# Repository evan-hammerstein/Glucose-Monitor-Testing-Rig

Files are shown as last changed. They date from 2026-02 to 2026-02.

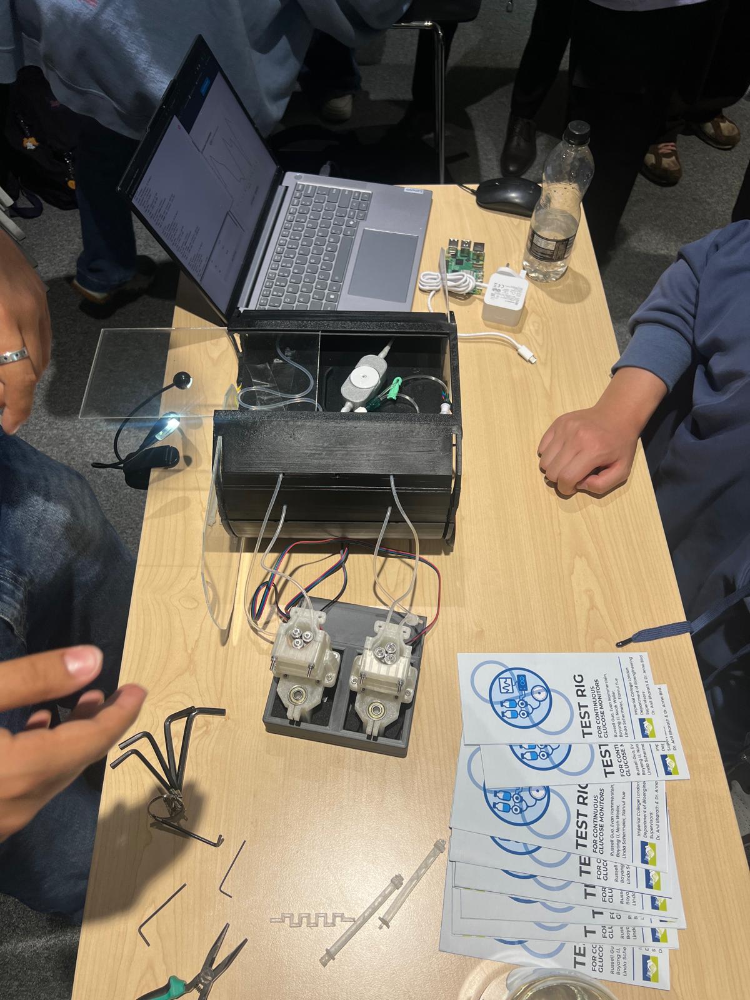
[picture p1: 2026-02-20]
real_build.jpeg

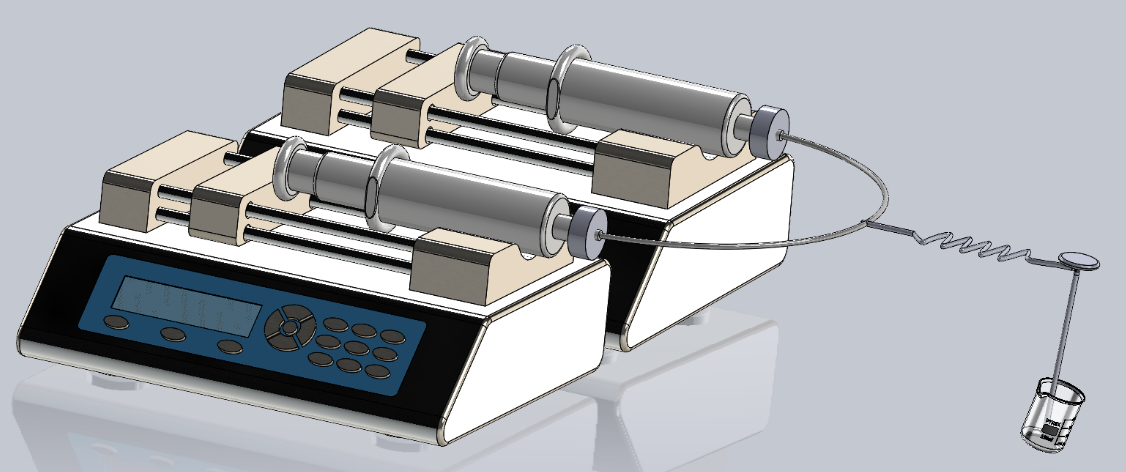
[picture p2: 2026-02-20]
syringe_pump_model.jpg

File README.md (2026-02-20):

# Design and Development of a Test Rig for Continuous Glucose Monitors (CGM)

**Associated Presentations and Full Project Report (Release):**

https://github.com/evan-hammerstein/Glucose-Monitor-Testing-Rig/releases/tag/Release
https://prezi.com/p/qimv-nsshvhj/?present=1

Imperial College London
MEng Bioengineering Final Year Project
Supervisors: Dr. Anil Bharath, Dr. Anna Bird

This repository contains all code, CAD models, control algorithms, circuit schematics, and supporting files for the design and validation of a cost-effective automated CGM test rig.

The full academic report is included in this repository and documents the complete design process and validation results .

---

# Project Overview

Continuous Glucose Monitors are increasingly used in diabetes management. However, early-stage CGM validation often relies on manual in-vitro testing with limited dynamic capability.

This project designed and implemented:

• A low-cost automated CGM test rig
• Programmable glucose concentration control
• Two fluid delivery architectures
• Custom passive mixing solutions
• A CGM-compatible fluid interface
• An Arduino-based control system
• A desktop user interface for simulation and automation

Two complete systems were developed:

1. Binary system
   Alternates between two fixed glucose concentrations.

2. Dynamic system
   Recreates physiologically realistic glucose trajectories using real-time flow rate control based on the Padova model.

---

# Key Features

• Fully automated glucose profile generation
• Real-time pump control via Arduino
• Open-source peristaltic pump integration
• Custom 3D-printed passive mixers
• CGM interface designed for leak-free operation
• Electron-based desktop UI
• Integration with FreeStyle Libre 2 CGM
• Modular design using Luer-lock fluidics

---

# Repository Structure

/3D-Models
• Passive mixer designs
• CGM interface designs
• Peristaltic pump customizations
• STL and CAD files

/arduino
• Binary valve control code
• Dynamic dual-pump control algorithm
• RPM mapping implementation
• Delay synchronization logic

/electron-ui
• User interface for profile selection
• Parameter configuration
• Glucose trajectory visualization

/python
• Padova model integration
• Example glucose profiles
• CSV generation for simulation

/circuits
• Valve control schematics
• Dual pump A4988 driver circuit
• Wiring diagrams

/report
• Final project report (PDF)

---

# System Architecture

Binary System

Syringe Pump → Solenoid Valves → CGM Interface → CGM Reader

Dynamic System

Peristaltic Pump 1
Peristaltic Pump 2
→ Y-junction → Passive Mixer → CGM Interface → CGM Reader

The dynamic system adjusts the ratio of high and low glucose reservoirs in real time to match a target glucose concentration trajectory.

---

# Control Algorithm Summary

Inputs:

• Composite flow rate
• Tubing geometry
• Reservoir concentrations
• Target glucose profile

Outputs:

• Individual pump flow rates
• Stepper motor RPM
• Pump activation delay

The algorithm ensures:

• Constant total flow rate
• Complementary pump behavior
• Synchronized arrival at mixing junction

Edge cases such as zero-flow conditions are handled explicitly.

---

# Hardware Components

• Arduino Uno
• A4988 stepper motor drivers
• NEMA 17 stepper motors
• Open-source peristaltic pump
• Solenoid valves
• Silicone tubing
• Luer connectors
• 3D-printed CGM interface
• FreeStyle Libre 2 CGM

Full bill of materials is included in the repository.

---

# Mixer Designs

Four passive mixer iterations were evaluated:

• Stepwise geometry
• Sinusoidal channel
• Helical in-line mixer
• Self-constructed multi-loop mixer

The self-constructed multi-loop mixer provided:

• Effective mixing
• Ease of fabrication
• Leak-free integration
• Compatibility with standard lab printers

---

# Validation Highlights

• Pump RPM vs flow rate linear correlation: R = 0.9998
• Mixer absorbance matched magnetically stirred control
• Open-channel CGM interface demonstrated leak-free operation
• Binary system successfully reproduced square-wave profiles
• Dynamic system tracked programmed glucose trajectories

Observed deviations were attributed to:

• CGM internal processing
• Diffusion delays
• Environmental effects
• Delay amplification under certain parameter combinations

---

# How to Use

1. Assemble hardware using provided CAD and material lists
2. Upload Arduino firmware
3. Connect pumps and drivers per circuit diagrams
4. Launch Electron UI
5. Select or generate glucose profile
6. Run system
7. Monitor CGM output via xDrip+

---

# Applications

• Early-stage CGM validation
• Sensor accuracy testing
• Interference testing
• Algorithm verification
• Closed-loop system research
• CGM cybersecurity testing
• Hybrid closed loop simulation

---

# Future Improvements

• Improved delay minimization algorithm
• Automatic optimization of reservoir concentrations
• Environmental control integration
• Expanded flow rate characterization
• Diffusion vs advection quantification
• Closed-loop insulin simulation support

---

# Acknowledgements

Imperial College London
Department of Bioengineering

Supervisors:
Dr. Anil Bharath
Dr. Anna Bird

IN-CYPHER Programme

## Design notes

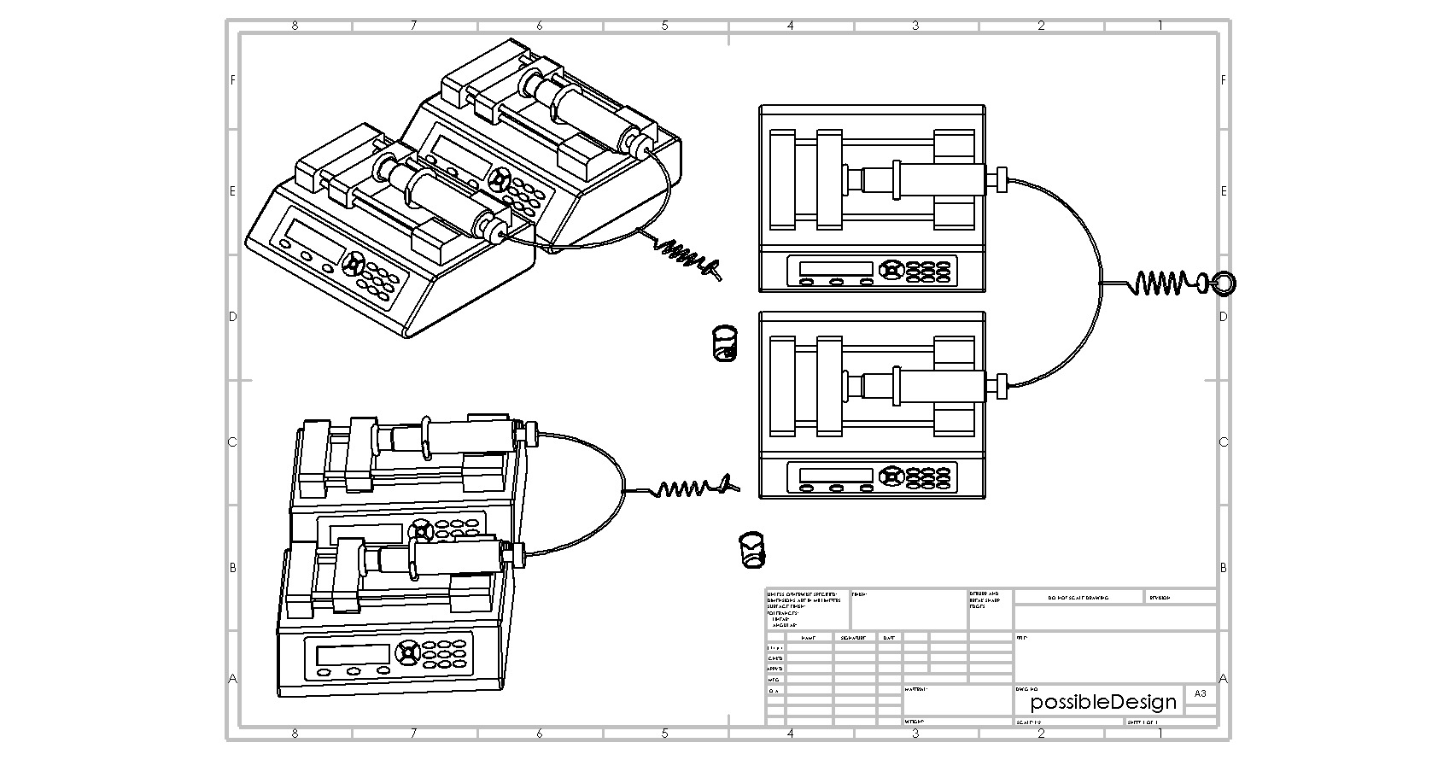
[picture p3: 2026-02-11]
Working in progress casing/possibleDesign.JPG

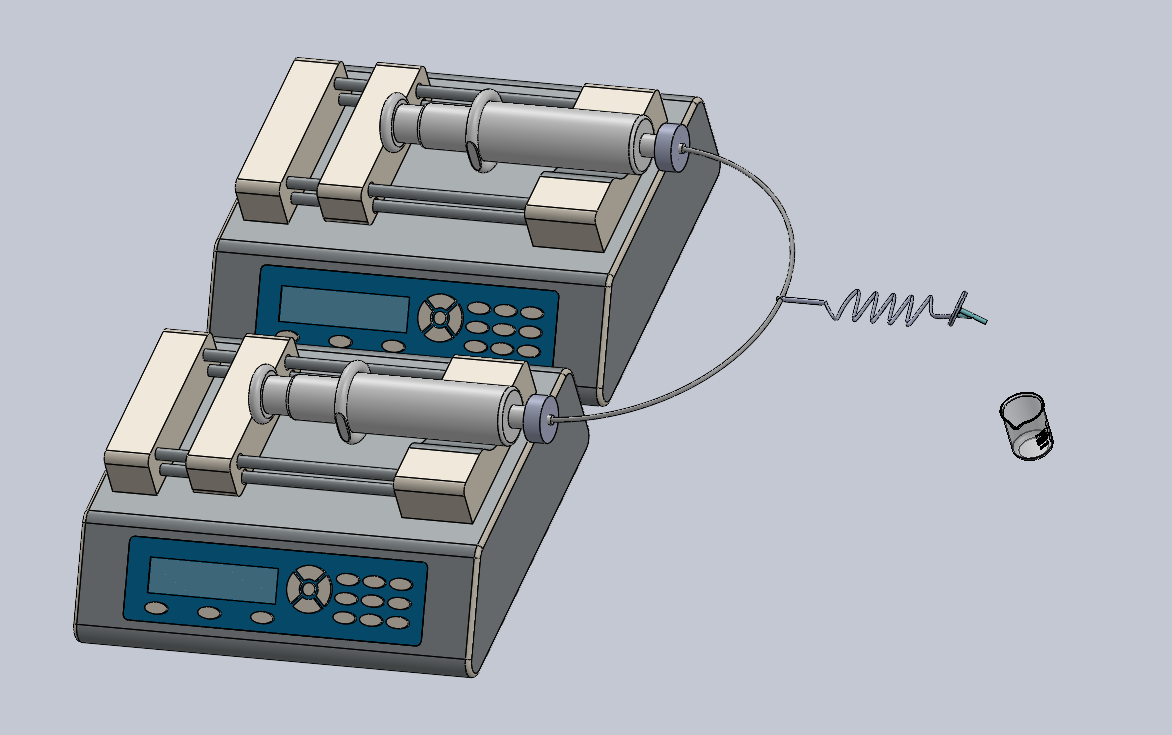
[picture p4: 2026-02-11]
Working in progress casing/possibleDesign.png

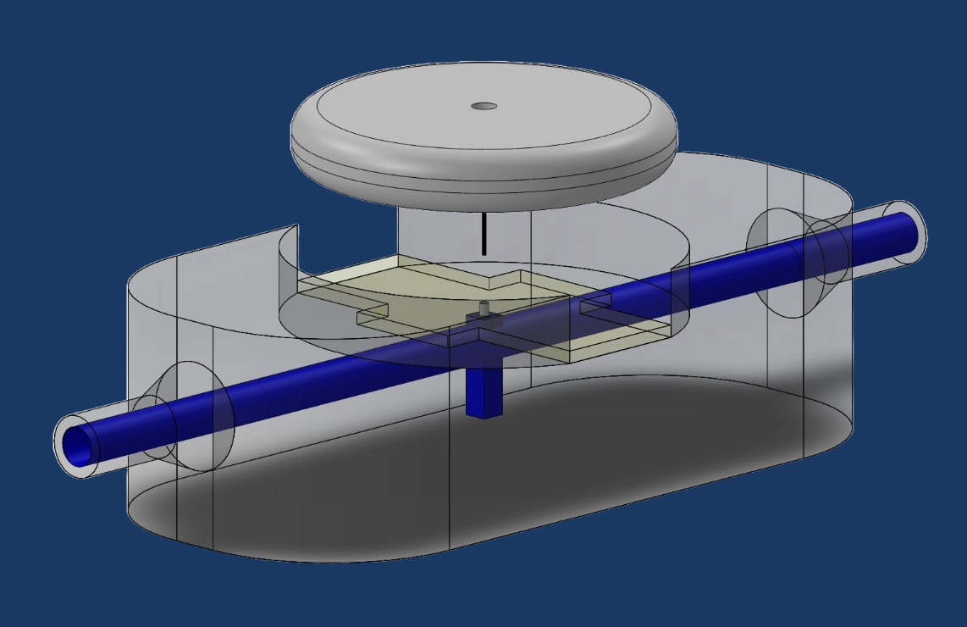
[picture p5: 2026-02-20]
cgm_interface.jpg

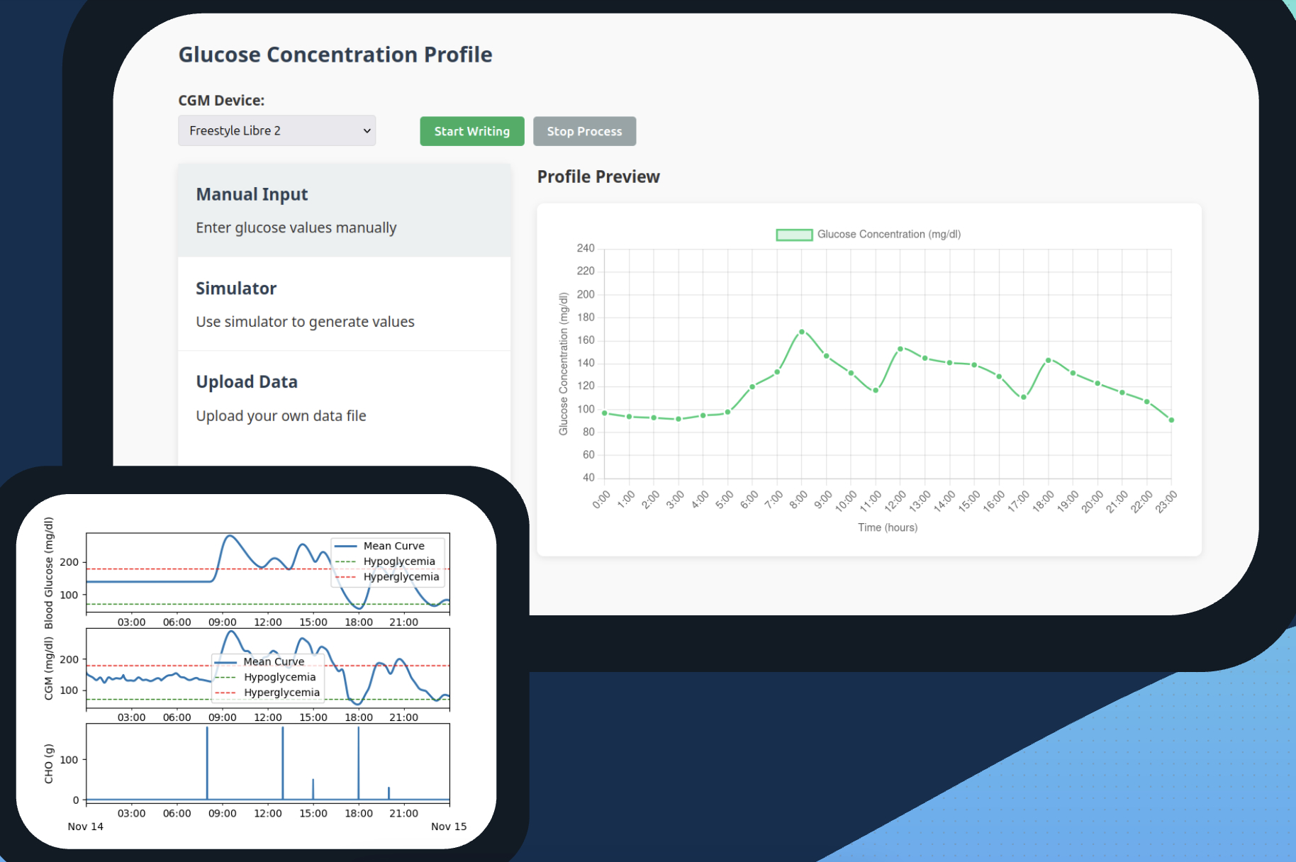
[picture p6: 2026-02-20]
ui_sample.jpg

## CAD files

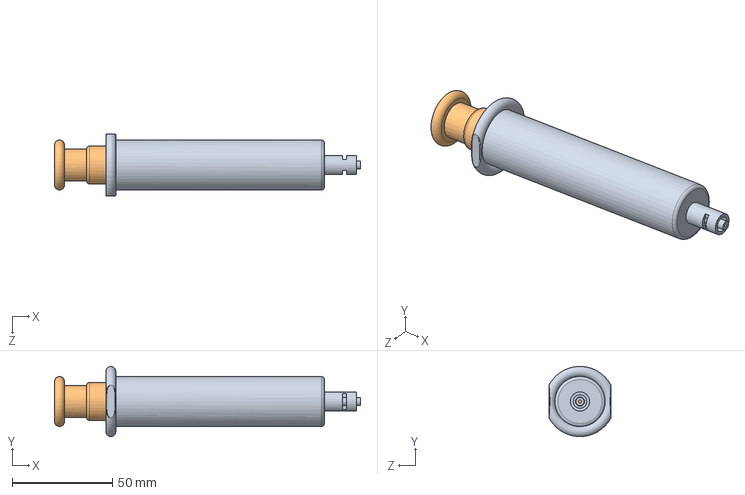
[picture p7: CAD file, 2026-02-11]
Syringe Pump/20mL - Glass Syringe.SLDASM
152.6 x 35.0 x 31.0 mm
20mL - Glass Barrel
20mL - Glass Syringe Plunger

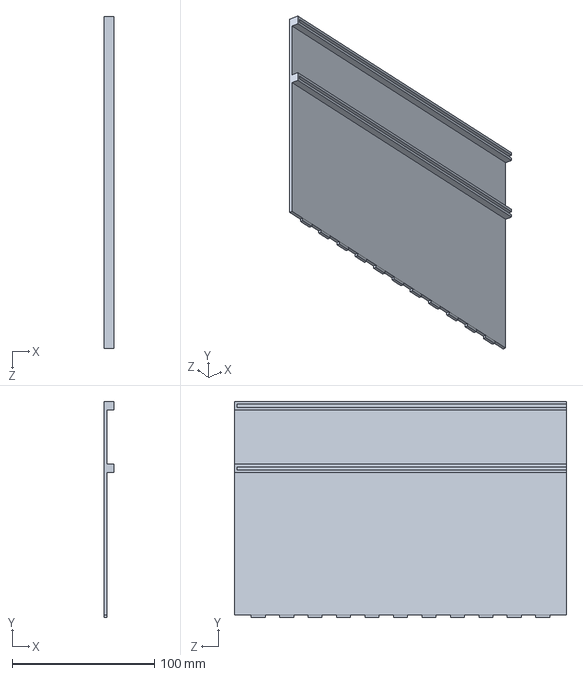
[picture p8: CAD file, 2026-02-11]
Casing/Casing/Side_board_right.SLDPRT
7.20 x 151.8 x 233.6 mm

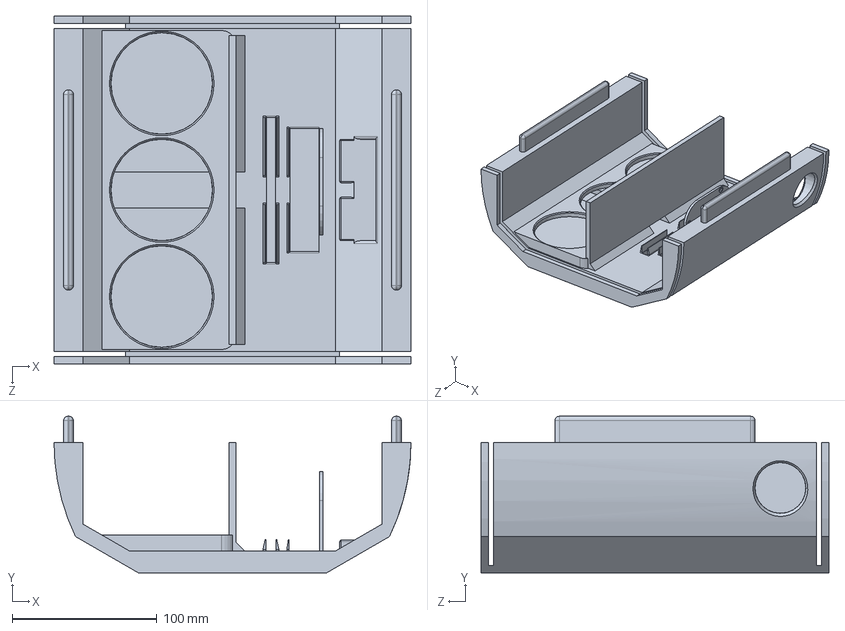
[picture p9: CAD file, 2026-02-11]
Casing/finalassem/possible3Dbottom3.SLDPRT
246.2 x 108.0 x 240.0 mm

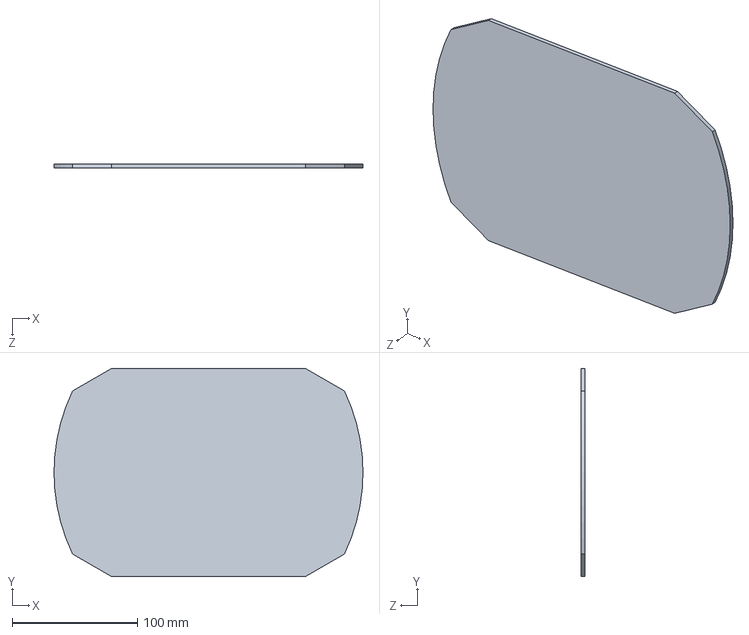
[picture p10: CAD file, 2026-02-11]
Casing/slidingbit.SLDPRT
246.2 x 166.0 x 3.00 mm

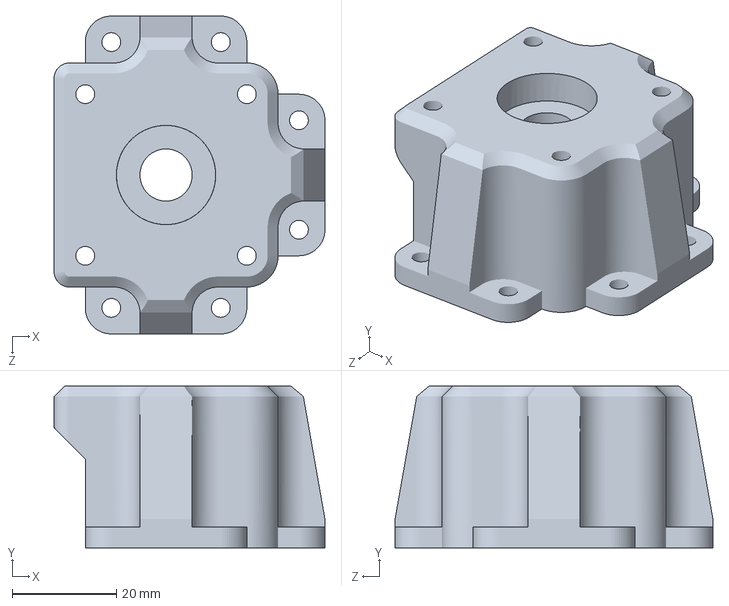
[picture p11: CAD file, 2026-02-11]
peristaltic/case_19.05x.SLDPRT
52.0 x 31.0 x 61.0 mm

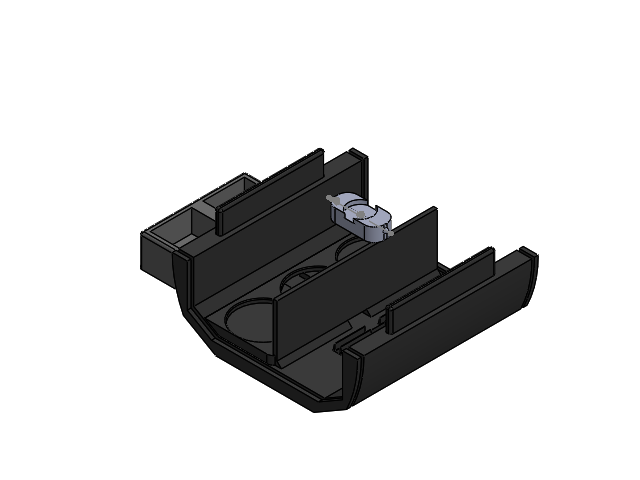
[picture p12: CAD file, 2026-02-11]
Casing/Assem1.SLDASM
possible3D
AnnaInterface_pt1 - Noah Edit with bottom + seal and housing for the sensor V10
Pump holder

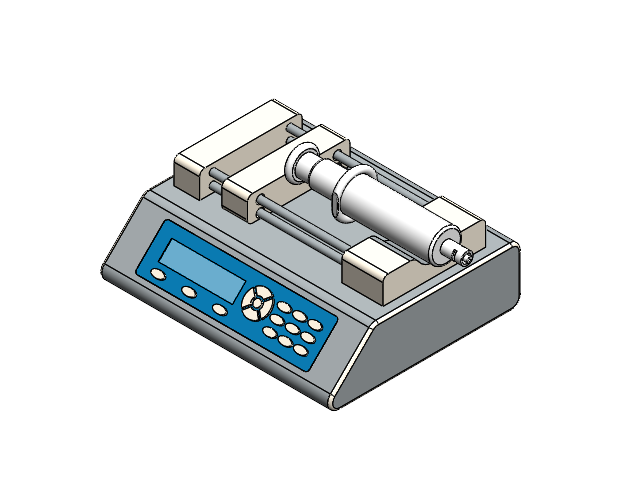
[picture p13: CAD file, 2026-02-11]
Syringe Pump/New folder/Syringe pump with luer lock syringe one.SLDASM
Pusher Block
User Interface
20mL - Glass Barrel
20mL - Glass Syringe Plunger

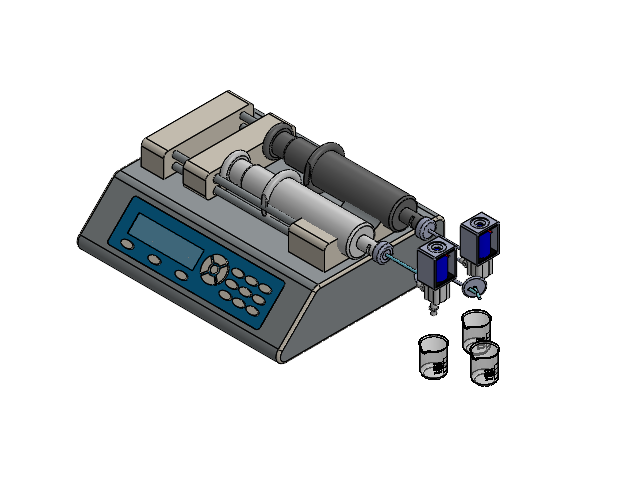
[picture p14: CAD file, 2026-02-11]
Casing/custom2USED.SLDASM
Pusher Block
User Interface
20mL - Glass Barrel x 2
20mL - Glass Syringe Plunger x 2
Pipe
Valveeee x 2
valve int
Y-Valve
Freestyle Libre 2
200ml Glass Beaker x 3

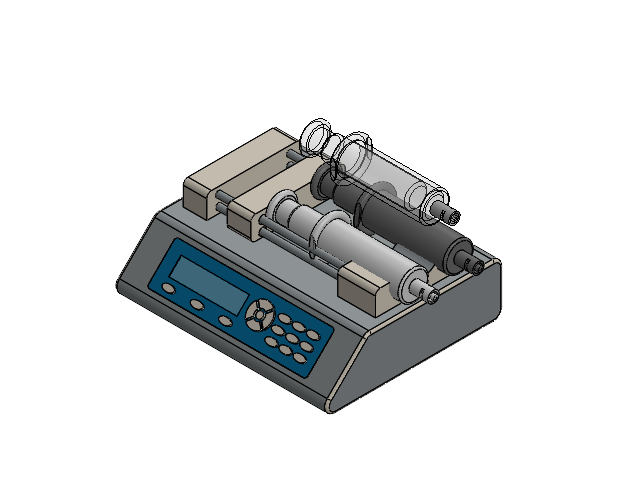
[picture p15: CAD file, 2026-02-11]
Syringe Pump/custompump.SLDASM
Pusher Block
User Interface
20mL - Glass Barrel x 2
20mL - Glass Syringe Plunger x 2

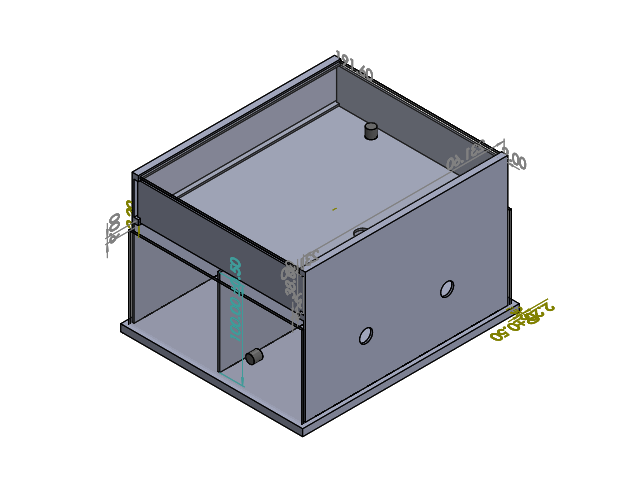
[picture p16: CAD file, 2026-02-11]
Working in progress casing/Enclosure_assembly.SLDASM
Bottom_base
Side_board_left
Side_board_middle
Sliding_board_side x 2
Side_board_right
Sliding_board_upper
Sliding_board_top

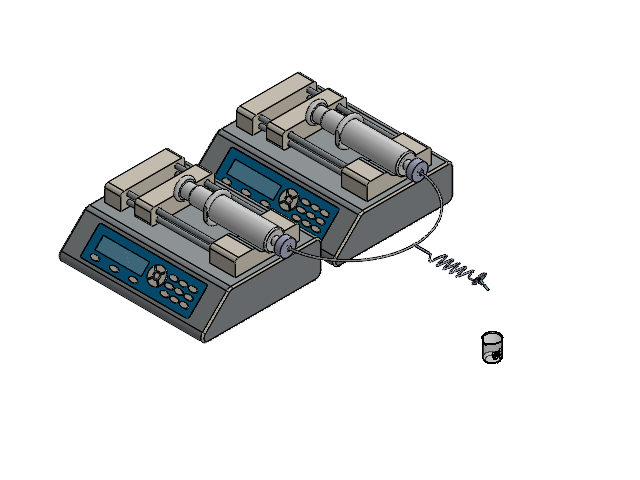
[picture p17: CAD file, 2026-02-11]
Syringe Pump/New folder/possibleDesign.SLDASM
Pusher Block x 2
User Interface x 2
20mL - Glass Barrel x 2
20mL - Glass Syringe Plunger x 2
idealsysconnection
mixer
Y-Valve
Freestyle Libre 2
200ml Glass Beaker

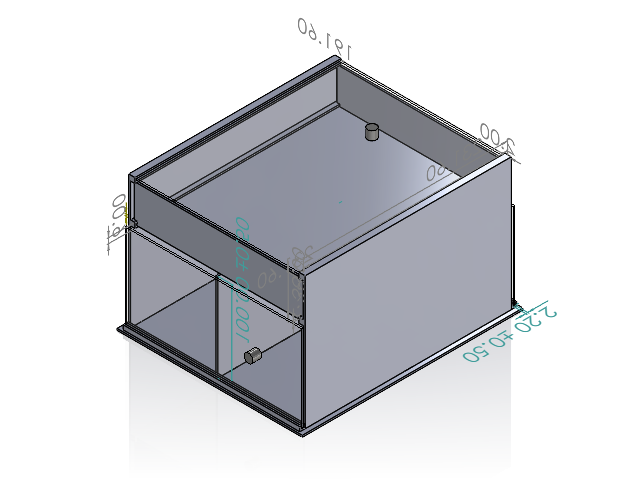
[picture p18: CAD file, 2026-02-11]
Casing/Casing/Enclosure_assembly.SLDASM
Bottom_base
Side_board_left
Side_board_middle
Sliding_board_side x 2
Side_board_right
Sliding_board_upper
Sliding_board_top

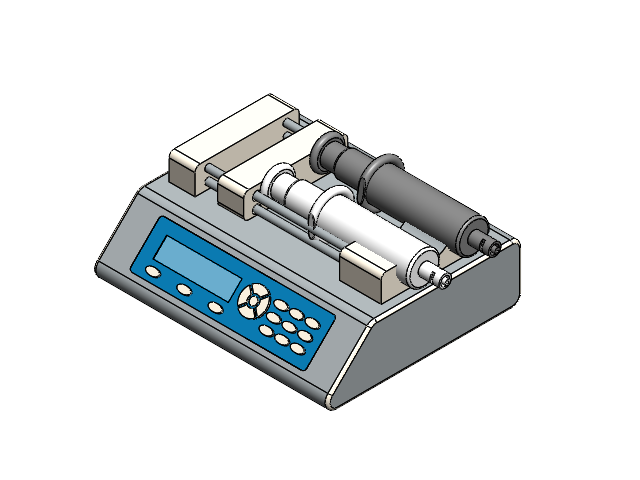
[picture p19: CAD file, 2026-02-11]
Syringe Pump/Syringe pump with luer lock syringe.SLDASM
Pusher Block
User Interface
20mL - Glass Barrel x 2
20mL - Glass Syringe Plunger x 2

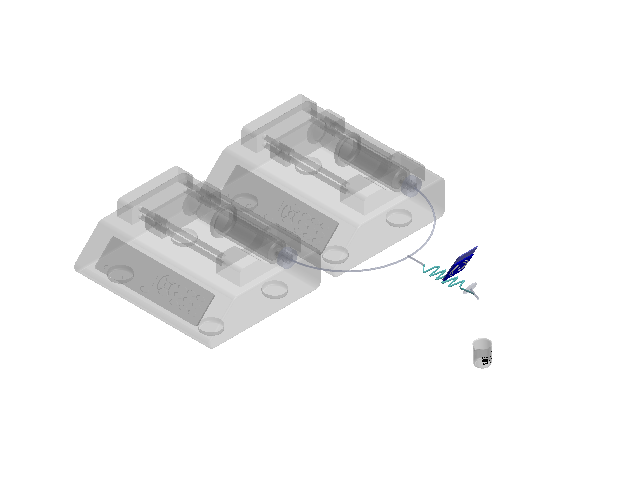
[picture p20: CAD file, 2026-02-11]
Working in progress casing/possibleDesign.SLDASM
Pusher Block x 2
User Interface x 2
20mL - Glass Barrel x 2
20mL - Glass Syringe Plunger x 2
idealsysconnection
mixer
Y-Valve
Freestyle Libre 2
200ml Glass Beaker
NFC READER

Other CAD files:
Syringe Pump/Syringe pump with luer lock syringe one.SLDASM
Syringe Pump/possibleDesign.SLDASM
Syringe Pump/custom2USED.SLDASM
Casing/custompump.SLDASM
Casing/AnnaInterface_pt1 - Noah Edit with bottom + seal and housing for the sensor V10.SLDPRT
Casing/Beaker.SLDPRT
Casing/Casing/Bottom_base.SLDPRT
Casing/Casing/Side_board_left.SLDPRT
Casing/Casing/Side_board_middle.SLDPRT
Casing/Casing/Sliding_board_side.SLDPRT
Casing/Casing/Sliding_board_top.SLDPRT
Casing/Casing/Sliding_board_upper.SLDPRT
Casing/Casing/possible3Dbottom3.STL
Casing/Casing/possible3Dtop3.STL
Casing/Freestyle Libre 2.SLDPRT
Casing/NFC READER.SLDPRT
Casing/Pump holder.SLDPRT
Casing/Pump holder.STL
Casing/badgeholder.SLDPRT
Casing/badgeholder.STL
Casing/custom2USEDdraw.SLDDRW
Casing/finalassem/100ml_BEAKER_M_1.SLDPRT
Casing/finalassem/9V-battery.SLDPRT
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

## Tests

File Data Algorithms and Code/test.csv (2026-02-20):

Time (min) | Concentration (µM)
0 | 24
0.5 | 38
1 | 59
1.5 | 38
2 | 24
2.5 | 38
3 | 59
3.5 | 38
4 | 24

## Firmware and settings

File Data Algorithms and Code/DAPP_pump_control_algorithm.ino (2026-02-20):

#define MAX_ENTRIES 100

// ---------- Global Storage ----------
int timestamps[MAX_ENTRIES];
float concentrations[MAX_ENTRIES];
int currentIndex = 0;

float compositeFlowRate_mLmin = 0.1;  // Main input!
float currentGlucoseFlowRate_mLmin = 0.0;
float currentPBSFlowRate_mLmin = 0.0;

float channelInternalDiameter_mm = 1.5;
float preIntersectionChannelLength_mm = 100.0;

String inputBuffer = "";
bool dataReceived = false;

// ---------- Setup ----------
void setup() {
  Serial.begin(9600);
  while (!Serial);
  Serial.println("Ready to receive CSV data...");
}

// ---------- Loop ----------
void loop() {
  if (!dataReceived) {
    while (Serial.available()) {
      char c = Serial.read();
      if (c == '\n') {
        processLine(inputBuffer);
        inputBuffer = "";
      } else {
        inputBuffer += c;
      }
    }

    if (currentIndex > 0 && !Serial.available()) {
      dataReceived = true;
      Serial.println("CSV received. Running schedule...");
      runPumpSchedule();
    }
  }
}

// ---------- Parse CSV Line ----------
void processLine(String line) {
  int commaIndex = line.indexOf(',');
  if (commaIndex == -1 || currentIndex >= MAX_ENTRIES) {
    Serial.println("Invalid line or buffer full.");
    return;
  }

  timestamps[currentIndex] = line.substring(0, commaIndex).toInt();
  concentrations[currentIndex] = line.substring(commaIndex + 1).toFloat();
  currentIndex++;
}

// ---------- Convert Composite Flow Rate → Velocity ----------
float convertFlowRateToVelocity(float totalFlowRate_mLmin, float innerDiameter_mm) {
  float Q_total = totalFlowRate_mLmin / (1e6 * 60.0);  // m³/s
  float diameter_m = innerDiameter_mm / 1000.0;
  float radius = diameter_m / 2.0;
  float area = 3.14159 * radius * radius;  // m²
  float velocity_m_per_sec = Q_total / area;
  return velocity_m_per_sec * 1000.0;  // mm/s
}

// ---------- Flow Rate Calculator ----------
void calculatePumpFlowRates_mLmin(float compositeFlowRate_mLmin, float desiredConc, float C1, float C2) {
  float Q_total = compositeFlowRate_mLmin / (1e6 * 60.0);  // m³/s
  float deltaC = C1 - C2;
  float Q1 = (deltaC != 0) ? Q_total * (desiredConc - C2) / deltaC : 0;
  float Q2 = Q_total - Q1;

  currentGlucoseFlowRate_mLmin = Q1 * 1e6 * 60.0;
  currentPBSFlowRate_mLmin = Q2 * 1e6 * 60.0;
}

// ---------- Delay Calculator ----------
void getPumpDelays_ms(float flowRate1_mLmin, float flowRate2_mLmin, float innerDiameter_mm, float channelLength_mm, int &delay1_ms, int &delay2_ms) {
  float Q1 = flowRate1_mLmin / (1e6 * 60.0);
  float Q2 = flowRate2_mLmin / (1e6 * 60.0);

  float diameter_m = innerDiameter_mm / 1000.0;
  float radius = diameter_m / 2.0;
  float area = 3.14159 * radius * radius;

  float v1 = (Q1 > 0) ? Q1 / area : 0;
  float v2 = (Q2 > 0) ? Q2 / area : 0;

  float t1 = (v1 > 0) ? (channelLength_mm / 1000.0) / v1 : -1;
  float t2 = (v2 > 0) ? (channelLength_mm / 1000.0) / v2 : -1;

  delay1_ms = 0;
  delay2_ms = 0;

  if (t1 < 0 || t2 < 0) return;

  if (t1 > t2) {
    delay2_ms = (int)((t1 - t2) * 1000);
  } else if (t2 > t1) {
    delay1_ms = (int)((t2 - t1) * 1000);
  }
}

// ---------- Main Control Loop ----------
void runPumpSchedule() {
  for (int i = 0; i < currentIndex; i++) {
    float targetConc = concentrations[i];

    // Calculate individual pump flows
    calculatePumpFlowRates_mLmin(compositeFlowRate_mLmin, targetConc, 0.020, 0.0);

    // Calculate delay to synchronize arrivals
    int delay1 = 0;
    int delay2 = 0;
    getPumpDelays_ms(currentGlucoseFlowRate_mLmin, currentPBSFlowRate_mLmin,
                     channelInternalDiameter_mm, preIntersectionChannelLength_mm,
                     delay1, delay2);

    // Output for now (replace with pump control logic later)
    Serial.print("At time ");
    Serial.print(timestamps[i]);
    Serial.print("s | Target Conc: ");
    Serial.print(targetConc);
    Serial.print(" M | Glucose: ");
    Serial.print(currentGlucoseFlowRate_mLmin, 3);
    Serial.print(" mL/min | PBS: ");
    Serial.print(currentPBSFlowRate_mLmin, 3);
    Serial.print(" mL/min | Delays → G: ");
    Serial.print(delay1);
    Serial.print(" ms, P: ");
    Serial.print(delay2);
    Serial.println(" ms");

    delay(1000); // simulate time between actions
  }
}

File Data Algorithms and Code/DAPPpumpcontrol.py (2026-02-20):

import serial
import time
import logging
import pandas as pd
import DAPPpumpcontrolfunctions as dapp

# -------------------------------
# CONFIGURE SERIAL PORTS (Change as needed)
# -------------------------------
GLUCOSE_PUMP_PORT = "COM3"  # Replace with actual COM port
BUFFER_PUMP_PORT = "COM4"   # Replace with actual COM port
BAUDRATE = 9600  # Harvard Apparatus standard baud rate

# --------------------
#   START RUNNING
# --------------------

# Connect both pumps
glucose_pump = dapp.initialize_serial(GLUCOSE_PUMP_PORT)
buffer_pump = dapp.initialize_serial(BUFFER_PUMP_PORT)

#read .csv file
dapp.read_concentration_csv("test.csv")



# -------------------------------
# RUN A TEST EXPERIMENT
# -------------------------------
if __name__ == "__main__":
    logging.basicConfig(level=logging.INFO)  # Enable logging

    # Example: Infuse glucose at 5 mL/min and buffer at 10 mL/min, with 20 mm syringe
    dapp.control_pumps(glucose_rate=5, buffer_rate=10, syringe_diameter=20)

    # Close serial connections
    glucose_pump.close()
    buffer_pump.close()
    logging.info("Serial connections closed.")




# I want my max concentration to be 33 mmol/L

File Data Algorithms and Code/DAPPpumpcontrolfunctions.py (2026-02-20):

import serial
import time
import logging
import pandas as pd

# -------------------------------
# CONFIGURE SERIAL PORTS (Change as needed)
# -------------------------------
GLUCOSE_PUMP_PORT = "COM3"  # Replace with actual COM port
BUFFER_PUMP_PORT = "COM4"   # Replace with actual COM port
BAUDRATE = 9600  # Harvard Apparatus standard baud rate

# -------------------------------
# INITIALIZE SERIAL CONNECTION
# -------------------------------
def initialize_serial(port):
    """Initialize RS-232 serial communication with the pump."""
    logging.info(f"Trying to connect for pump {port}")
    try:
        ser = serial.Serial(port, baudrate=BAUDRATE, stopbits=2, timeout=2)
        logging.info(f"Connected to pump on {port}")
        return ser
    except Exception as e:
        logging.error(f"Error connecting to pump on {port}: {e}")
        exit()

# -------------------------------
# SEND COMMANDS TO PUMPS
# -------------------------------
def send_command(pump, command):
    """Send a command to the pump and return the response."""
    pump.write((command + "\r").encode())  # Append carriage return
    time.sleep(0.1)  # Allow time for processing
    response = pump.read_all().decode().strip()
    logging.info(f"Sent: {command} | Response: {response}")
    return response

def set_flow_rate(pump, rate, units="MM"):
    """Set the pump's flow rate (Default: mL/min)."""
    send_command(pump, f"RAT {rate} {units}")

def set_syringe_diameter(pump, diameter = 1.5):
    """Set the syringe diameter (mm)."""
    send_command(pump, f"DIA {diameter}")

def start_pump(pump):
    """Start the pump infusion."""
    send_command(pump, "RUN")

def stop_pump(pump):
    """Stop the pump."""
    send_command(pump, "STP")

def get_status(pump):
    """Get pump status."""
    return send_command(pump, "DIS")

# -------------------------------
# GET DATA FROM USER
# -------------------------------
import pandas as pd

def read_concentration_csv(filepath):
    """
    Reads a CSV file and extracts concentration data.
    
    Parameters:
    - filepath (str): Path to the CSV file.

    Returns:
    - concentrations (list): List of concentration values from the CSV.
    - time_values (list): List of time values if available, else None.
    """
    try:
        # Read CSV file
        df = pd.read_csv(filepath)

        # Automatically detect the column containing concentrations
        concentration_columns = [col for col in df.columns if "concentration" in col.lower()]
        
        if not concentration_columns:
            raise ValueError("No concentration column found in the CSV file.")

        # Extract concentration data (assume first matching column)
        concentrations = df[concentration_columns[0]].tolist()
        
        # Try to extract time values if a "time" column exists
        time_columns = [col for col in df.columns if "time" in col.lower()]
        time_values = df[time_columns[0]].tolist() if time_columns else None
        
        print(f"Successfully read {len(concentrations)} data points from {filepath}")
        print (concentrations[0])
        return time_values, concentrations

    except Exception as e:
        print(f"Error reading file: {e}")
        return None, None

def calculate_delay(PBS_FLOWRATE, GLUCOSE_FLOWRATE, LENGTH):
    PBS_TIME = LENGTH/PBS_FLOWRATE
    GLUCOSE_TIME = LENGTH/GLUCOSE_FLOWRATE
    GLUCOSE_DELAY = max(0, (PBS_TIME-GLUCOSE_TIME))
    PBS_DELAY = max(0, (GLUCOSE_TIME-PBS_TIME))
    return GLUCOSE_DELAY, PBS_DELAY
        


# -------------------------------
# SET UP AND RUN PUMPS
# -------------------------------
def control_pumps(glucose_rate, buffer_rate, syringe_diameter):
    """Control both pumps dynamically."""
    
    # Set syringe diameter (Ensure both pumps use the same syringe size)
    set_syringe_diameter(glucose_pump, syringe_diameter)
    set_syringe_diameter(buffer_pump, syringe_diameter)

    # Set initial flow rates
    set_flow_rate(glucose_pump, glucose_rate)
    set_flow_rate(buffer_pump, buffer_rate)

    # Start both pumps
    start_pump(glucose_pump)
    start_pump(buffer_pump)
    
    logging.info(f"Pumps started | Glucose: {glucose_rate} mL/min | Buffer: {buffer_rate} mL/min")

    # Run for a fixed time, then stop
    time.sleep(60)  # Adjust based on experiment duration
    
    stop_pump(glucose_pump)
    stop_pump(buffer_pump)

    logging.info("Pumps stopped")

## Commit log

2026-02-11 CAD File Upload
    [100ml_BEAKER_M_1.SLDPRT, 200ml Glass Beaker.SLDPRT, 20mL - Glass Barrel.SLDPRT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]
2026-02-20 Added Code and App
    [200ml Glass Beaker.SLDPRT, 20mL - Glass Barrel.SLDPRT, 20mL - Glass Syringe Plunger.SLDPRT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]
